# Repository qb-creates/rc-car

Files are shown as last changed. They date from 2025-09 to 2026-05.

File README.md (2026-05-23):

# RC Car Project
This project is a custom-built remote-controlled (RC) car, designed from the ground up with custom electronics, PCB design, and embedded firmware for both the car and its remote.

- Project Video (YouTube): https://youtu.be/qdBbDeDglmY
- Bidirectional Motor Driver (H-Bridge): https://en.wikipedia.org/wiki/H-bridge
- Steering Servo PWM Control: https://en.wikipedia.org/wiki/Servo_control
- nRF24L01 Wireless Transceiver Module: https://www.instructables.com/NRF24L01-Tutorial-Arduino-Wireless-Communication/

<div align="center">
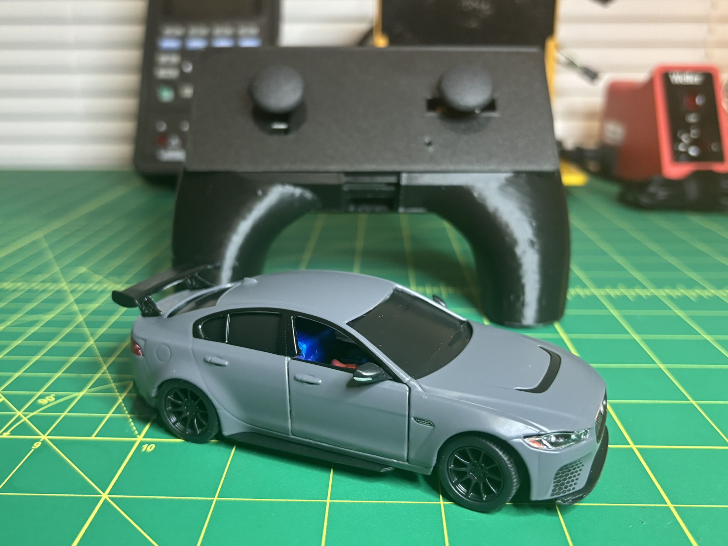
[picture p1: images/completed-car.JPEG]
Completed RC Car Side Profile
	
</div>

## Table of Contents
1. [Software Used](#software)
2. [Drive and Steering Control Circuit](#driveandsteeringcircuit)
    - [RF Receiver](#rfreceiver)
    - [Steering Servo Control](#steering)
    - [Drive Motor Control](#drivemotor)
    - [Power Consumption](#powerconsumption)
    - [Charging Notes](#carcharging)
    - [Parts List](#carpartslist)
    - [Schematics](#carschematics)
    - [PCB Images](#carpcbimages)
3. [Remote Control Circuit](#remotecontrolcircuit)
    - [RF Transmitter](#rftransmitter)
    - [Control Input Processing](#controlinputprocessing)
        - [Throttle Input (Left Analog Stick)](#throttleprocessing)
        - [Steering Input (Right Analog Stick)](#steeringprocessing)
    - [Charging Notes](#remotecharging)
    - [Parts List](#remotepartslist)
    - [Schematics](#remoteschematics)
    - [PCB Images](#remotepcbimages)
4. [Pin Mapping](#pinmapping)
    - [Car Controller (ATmega164A)](#carpinmapping)
    - [Remote Controller (ATmega164A)](#remotepinmapping)
5. [STL Viewer](#stlviewer)
    - [Car Mechanical Mounts STL](#carmechanicalmountsstl)
    - [Controller Housing STL](#controllerhousingstl)

## 1. Software Used
- VSCode with PlatformIO extension: https://docs.platformio.org/en/latest/what-is-platformio.html
- AVRDUDE (Flash Uploader): https://github.com/avrdudes/avrdude
- KiCad (PCB Design): https://www.kicad.org
- Tinkercad (Controller and parts Design): https://www.tinkercad.com/

## 2. Drive and Steering Control Circuit
This board is the car's real-time control core. It receives wireless throttle/steering commands from the handheld transmitter, converts steering targets into stable hardware PWM for the MG90S servo, and drives the rear motor through a protected H-bridge path with direction dead-time and command deadbands for smoother behavior. The result is a compact control system designed for responsive handling, predictable failsafe behavior, and reliable power delivery under changing load.

<div align="center">
 <table>
     <tr>
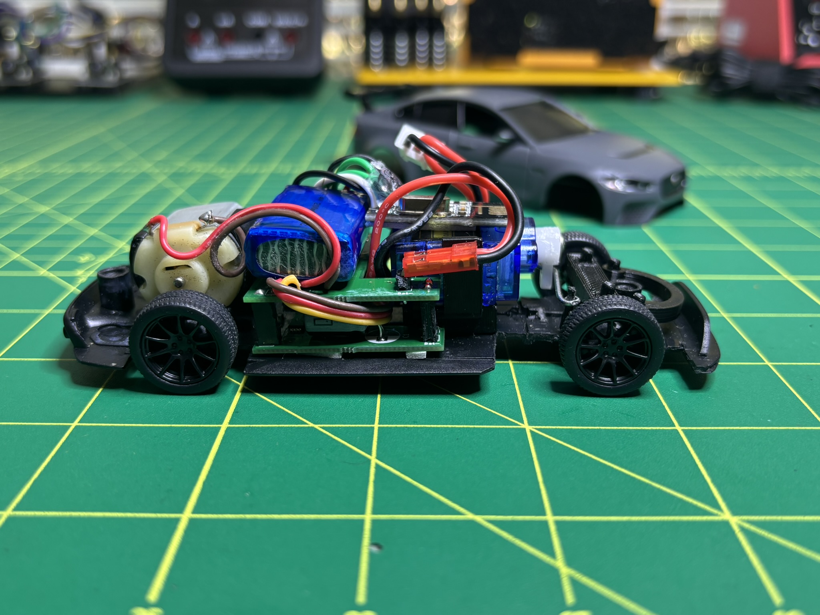
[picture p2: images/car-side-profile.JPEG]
Car Side Profile
         <td></td>
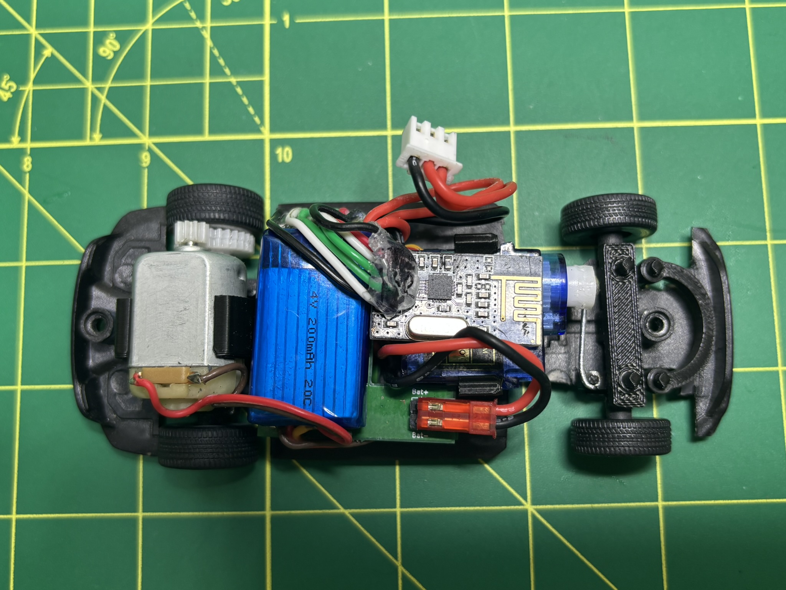
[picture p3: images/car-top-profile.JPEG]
Car Top Profile
         <td></td>
     </tr>
     <tr>
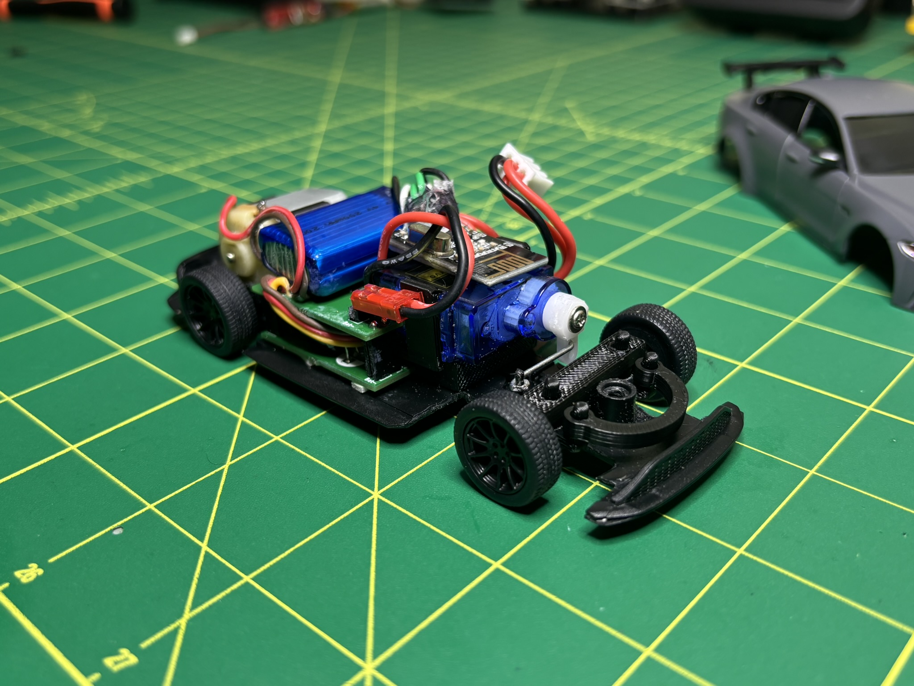
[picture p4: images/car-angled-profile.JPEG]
Car Angled Profile
         <td></td>
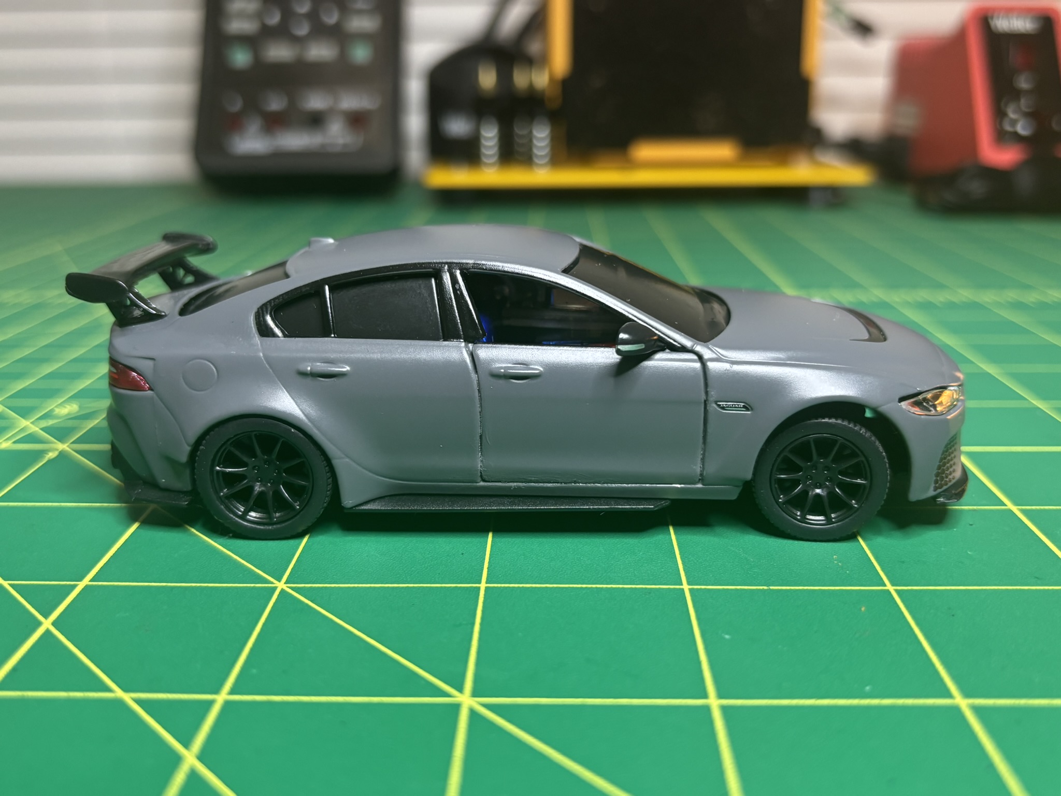
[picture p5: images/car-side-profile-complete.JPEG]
Car Side Profile Complete
         <td></td>
     </tr>
 </table>
</div>

### RF Receiver
The car uses an nRF24L01+ module with the RF24 library over SPI to receive drive and steering commands from the handheld controller. In firmware, the radio object is created as `RF24 radio(CE_PIN, CSN_PIN)` with CE on PB0 and CSN on PB1.

The RF stack is configured in `configureRFRadio()` with:

- `radio.begin()` hardware check (halts if radio is not detected)
- `radio.setPALevel(RF24_PA_LOW)` to reduce TX power/current
- `radio.enableDynamicPayloads()`
- `radio.setAutoAck(false)`
- Pipe/address setup using `"jag-1"` and `"jag-2"`
- `radio.startListening()` so this node stays in RX mode

An important part of the RF path is Timer0 timing configuration. Because this firmware includes `#include <RF24.h>`, the RF24 stack depends on `millis()`/`micros()` timing for operations such as CE pulse timing, transmit timing windows, retry timing, and transaction spacing.

The RF24 library itself does not directly configure Timer0. Instead, those timing primitives are provided by the Arduino core (`millis()`/`micros()`), and the project sets Timer0 for a 50 us timing base:

```cpp
TCCR0A = (1 << COM0B1) | (1 << WGM01) | (1 << WGM00);
TCCR0B = (1 << WGM02) | (1 << CS01); // prescaler = 8
OCR0A = 49;
```

At 8 MHz CPU clock with prescaler 8:

- Timer clock = 8 MHz / 8 = 1 MHz
- Timer tick = 1 us
- Period = (49 + 1) x 1 us = 50 us

So the Timer0 event period is 50 us (20 kHz). Timer0 is intentionally kept running at this rate so the `millis()`/`micros()` time base used by RF24 remains available and stable.

The receiver expects a `MotorControlPayload` packet with two fields:

- `int16_t ocrMotor` for signed throttle/drive command
- `uint16_t ocrSteering` for servo pulse width command in microseconds

This payload is 4 bytes total (`2 + 2`), and after reception the car firmware applies it directly:

- `OCR1B = payload.ocrSteering` for steering position
- `payload.ocrMotor` drives H-bridge direction/speed logic with a deadband of -15 to +15

Reliability/safety behavior tied to RF reception:

- On first valid packet, watchdog is enabled (`WDTO_2S`)
- Each additional valid packet resets the watchdog
- If RF packets stop arriving, watchdog timeout forces a reset/failsafe

### Steering Servo Control
Steering is driven by an MG90S servo using Timer1 hardware PWM on OC1B (PD4). The car firmware configures Timer1 in Fast PWM mode 14 with ICR1 as TOP, prescaler = 8, and ICR1 = 20000. With an 8 MHz clock, that gives a 1 us timer tick and about a 50 Hz control period (20 ms), which matches standard hobby servo timing.

The commanded steering pulse is written directly to OCR1B. Steering values are transmitted as absolute pulse widths in microseconds. Instead of assuming a fixed joystick center, the controller now supports calibration by entering measured joystick potentiometer voltages for minimum, maximum, and center. Those measured values are used to map ADC input to the steering pulse range and produce a more accurate neutral point (typically near 1900 us). On the car side, OCR1B is updated from the payload each loop:

- Neutral: calibrated from measured joystick center voltage (typically ~1900 us)
- Left/Right command range: ~1520 us to ~2280 us
- PWM period: ~20 ms (50 Hz)
- Steering deadzone: +/-90 us around calibrated center snaps to neutral to reduce twitch

This keeps steering response deterministic because the servo waveform is generated in hardware (Timer1), not by software toggling.

### Drive Motor Control
The drive motor uses a discrete H-bridge driven by a hybrid approach: latch lines select direction, while PWM is generated in software via Timer2 interrupts.

H-bridge signal assignment:

- PC0: Forward latch
- PC1: Forward PWM
- PC2: Reverse latch
- PC3: Reverse PWM

Timer2 is configured for Fast PWM with OCR2A as TOP. With OCR2A = 199 and prescaler = 8 at 8 MHz, PWM frequency is about 5 kHz. Instead of using OC2A/OC2B output pins directly, compare interrupts are used:

- TIMER2_COMPA_vect sets the active direction PWM pin high (PC1 for forward or PC3 for reverse)
- TIMER2_COMPB_vect clears that same active pin low

This effectively creates direction-dependent PWM on one of two output pins while the opposite side remains off.

Direction changes are intentionally staged to protect the bridge and drivetrain:

1. Disable Timer2 PWM (stop switching)
2. Force all H-bridge outputs low
3. Wait 150 ms dead-time
4. Assert new direction latch (PC0 forward or PC2 reverse)
5. Re-enable Timer2 PWM

That delay prevents hard instant reversals and helps ensure MOSFETs on the same side of the H-bridge are not on at the same time during direction transitions, reducing shoot-through/braking stress.

Additional control logic from the car firmware:

- Speed deadband: commands between -15 and +15 stop the motor to avoid joystick/noise creep
- Steering deadzone: commands within +/-90 us of the calibrated center are snapped to neutral
- Direction is only changed when needed (or from stopped state)
- A watchdog is enabled after first RF packet and reset on each valid packet; if RF traffic is lost, the MCU resets after the watchdog timeout (2 s)

### Why RF reception is harder with this PWM approach
Using Timer2 compare interrupts for every PWM cycle means the MCU is servicing frequent interrupts continuously while also polling and reading nRF24 payloads over SPI. That interrupt load can steal time from RF handling and make robust payload reception harder than a pure hardware-PWM motor path.

In practice, the current tuning (about 5 kHz PWM, deadband around zero, staged direction changes) was a workable sweet spot between motor smoothness and reliable radio updates. A strictly hardware PWM implementation for both drive channels would reduce ISR overhead and leave more CPU time for RF processing.

### Power Consumption
This power system was sized around worst-case drive events (motor stall plus active steering), not just average cruising current.

Estimated load envelope:

- 9V drive motor stall current at 7.2V: ~600 mA
- MG90S steering servo working current: ~600-700 mA
- Control circuitry (MCU, RF, logic, support electronics): ~20 mA

Worst-case instantaneous estimate:

- Total peak demand: $0.60 + 0.70 + 0.02 \approx 1.32\,A$

Battery capability:

- 2S 200 mAh pack, 20C rating
- Maximum continuous supply: $0.2\,Ah \times 20 = 4\,A$

Power-stage device headroom:

- IRLML6244 continuous drain current: 6.3 A (comfortably above motor stall current)
- IRLML2246 continuous source current: -1.3 A (above the ~600 mA motor stall requirement in this bridge path)

Conclusion: the battery and MOSFET current limits provide practical headroom over the expected peak load, so the system can supply drive, steering, and control electronics simultaneously under normal and transient operation.

### Charging Notes
For safe charging practice on the car side, do not charge the car while it is powered on. Turn the car off first, then connect the charger.

---
### Parts List
<div align="center">
    <table>
        <tr>
            <td valign="top">
                <table>
                    <tr><th>Part Number</th><th>Quantity</th></tr>
                    <tr><td><a href="https://www.digikey.com/en/products/detail/rubycon/25YXG220MEFC6-3X11/3134189">220uF Capacitor</a></td><td align="center">x1</td></tr>
                    <tr><td><a href="https://www.digikey.com/en/products/detail/taiyo-yuden/TMK107B7105KA-T/2714162">1uF Capacitor</a></td><td align="center">x2</td></tr>
                    <tr><td><a href="https://www.digikey.com/en/products/detail/samsung-electro-mechanics/CL21A106KAYNNNG/3894413">10uF Capacitor</a></td><td align="center">x1</td></tr>
                    <tr><td><a href="https://www.digikey.com/en/products/detail/murata-electronics/GRM188R61E225KA12D/4905349">2.2uF Capacitor</a></td><td align="center">x1</td></tr>
                    <tr><td><a href="https://www.digikey.com/en/products/detail/kemet/C0603C104K3RACTU/416044">.1uF Capacitor</a></td><td align="center">x4</td></tr>
                    <tr><td><a href="https://www.digikey.com/en/products/detail/venkel/CTL1206FRD1T/13245061">LED</a></td><td align="center">x1</td></tr>
                    <tr><td><a href="https://www.digikey.com/en/products/detail/diodes-incorporated/1N5819HW-7-F/814970">1N5819HW-7-F Diode</a></td><td align="center">x4</td></tr>
                    <tr><td><a href="https://www.amazon.com/2-54mm-Breakaway-Female-Connector-Arduino/dp/B01MQ48T2V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">Header Pins</a></td><td align="center">x17</td></tr>
                    <tr><td><a href="https://www.digikey.com/en/products/detail/onsemi/MMBT3904LT1G/919601">MMBT3904</a></td><td align="center">x2</td></tr>
                    <tr><td><a href="https://www.digikey.com/en/products/detail/umw/UMWIRLML2246TR/24889419">IRLML2246 / UMWIRLML2246TR</a></td><td align="center">x2</td></tr>
                    <tr><td><a href="https://www.digikey.com/en/products/detail/infineon-technologies/IRLML6244TRPBF/2393871">IRLML6244</a></td><td align="center">x2</td></tr>
                    <tr><td><a href="https://www.digikey.com/en/products/detail/stackpole-electronics-inc/RMCF0603FT470K/1761140">470k ohm Resistor</a></td><td align="center">x1</td></tr>
                    <tr><td><a href="https://www.digikey.com/en/products/detail/yageo/RC0603JR-07510KL/726802">500k ohm Resistor</a></td><td align="center">x1</td></tr>
                    <tr><td><a href="https://www.digikey.com/en/products/detail/koa-speer-electronics-inc/RK73B1JTTD154J/9844780">150k ohm Resistor</a></td><td align="center">x1</td></tr>
                    <tr><td><a href="https://www.digikey.com/en/products/detail/yageo/RC0603JR-071K5L/726689">1.5k ohm Resistor</a></td><td align="center">x1</td></tr>
                    <tr><td><a href="https://www.digikey.com/en/products/detail/stackpole-electronics-inc/RMCF0603JT10K0/1758104">10k ohm Resistor</a></td><td align="center">x5</td></tr>
                </table>
            </td>
            <td width="24"></td>
            <td valign="top">
                <table>
                    <tr><th>Part Number</th><th>Quantity</th></tr>
                    <tr><td><a href="https://www.digikey.com/en/products/detail/yageo/RC0603JR-071K3L/726686">1.3k ohm Resistor</a></td><td align="center">x4</td></tr>
                    <tr><td><a href="https://www.digikey.com/en/products/detail/stackpole-electronics-inc/RMCF0603FT10R0/1761152">10 ohm Resistor</a></td><td align="center">x2</td></tr>
                    <tr><td><a href="https://www.digikey.com/en/products/detail/omron-electronics-inc-emc-div/A6S-1104-PH/3102847">SW_SPST</a></td><td align="center">x1</td></tr>
                    <tr><td><a href="https://www.digikey.com/en/products/detail/texas-instruments/TPS3840DL35DBVR/15857118">TPS3840</a></td><td align="center">x1</td></tr>
                    <tr><td><a href="https://www.digikey.com/en/products/detail/microchip-technology/MIC3975-5-0YMM-TR/1029778">MIC3975-5.0YMM Voltage Regulator</a></td><td align="center">x1</td></tr>
                    <tr><td><a href="https://www.digikey.com/en/products/detail/microchip-technology/MIC5225-3-3YM5-TR/1815447">MIC5225-3.3YM5 Voltage Regulator</a></td><td align="center">x1</td></tr>
                    <tr><td><a href="https://www.digikey.com/en/products/detail/microchip-technology/ATMEGA164A-AU/2271202">ATmega164A-A</a></td><td align="center">x1</td></tr>
                    <tr><td><a href="https://www.amazon.com/dp/B0BWJ4RKGV?ref=ppx_yo2ov_dt_b_fed_asin_title">MG90S servo motor</a></td><td align="center">x1</td></tr>
                    <tr><td><a href="https://www.amazon.com/uxcell-Micro-11500-12000RPM-Remote-Control/dp/B07M99JK6Y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">9V DC Motor</a></td><td align="center">x1</td></tr>
                    <tr><td><a href="https://www.amazon.com/KiNSMART-Jaguar-Project-Metal-Model/dp/B0GXDP3B83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">Kinsmart Jaguar 1:38</a></td><td align="center">x1</td></tr>
                    <tr><td><a href="https://www.amazon.com/HiLetgo-NRF24L01-Wireless-Transceiver-Module/dp/B00LX47OCY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">NRF24L01+ Module</a></td><td align="center">x1</td></tr>
                    <tr><td><a href="https://www.amazon.com/dp/B07MW2L96L?ref=ppx_yo2ov_dt_b_fed_asin_title">7.4V battery</a></td><td align="center">x1</td></tr>
                    <tr><td><a href="https://www.amazon.com/200PCS-Module-Plastic-Single-Spindle/dp/B0DKHG96PL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">Gears</a></td><td align="center">x1</td></tr>
                    <tr><td><a href="https://www.amazon.com/ruthex-Threaded-Insert-pieces-ultrasound/dp/B088QJG676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">M2 Inserts</a></td><td align="center">x3</td></tr>
                    <tr><td><a href="https://www.amazon.com/Phillips-Countersunk-Electronic-Accessories-Samsung/dp/B07HC3LQYS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">M2 screws</a></td><td align="center">x3</td></tr>
                </table>
            </td>
        </tr>
    </table>
</div>

### Schematics
<div align="center">
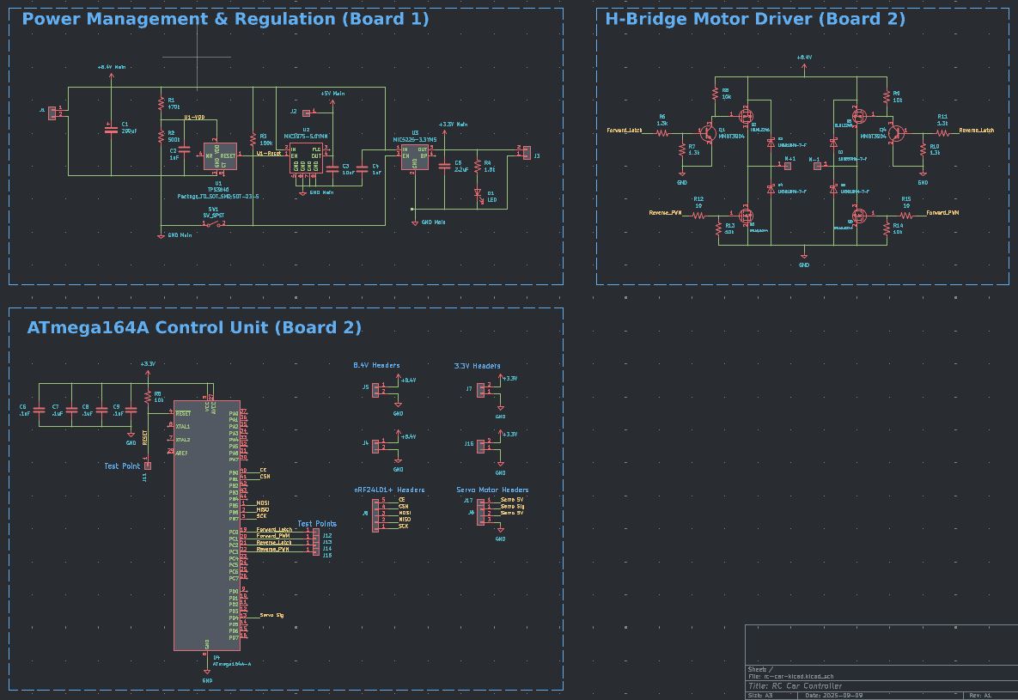
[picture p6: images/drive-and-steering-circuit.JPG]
Drive and Steering Circuit
    
</div>

### PCB Images
<div align="center">
 <table>
     <tr>
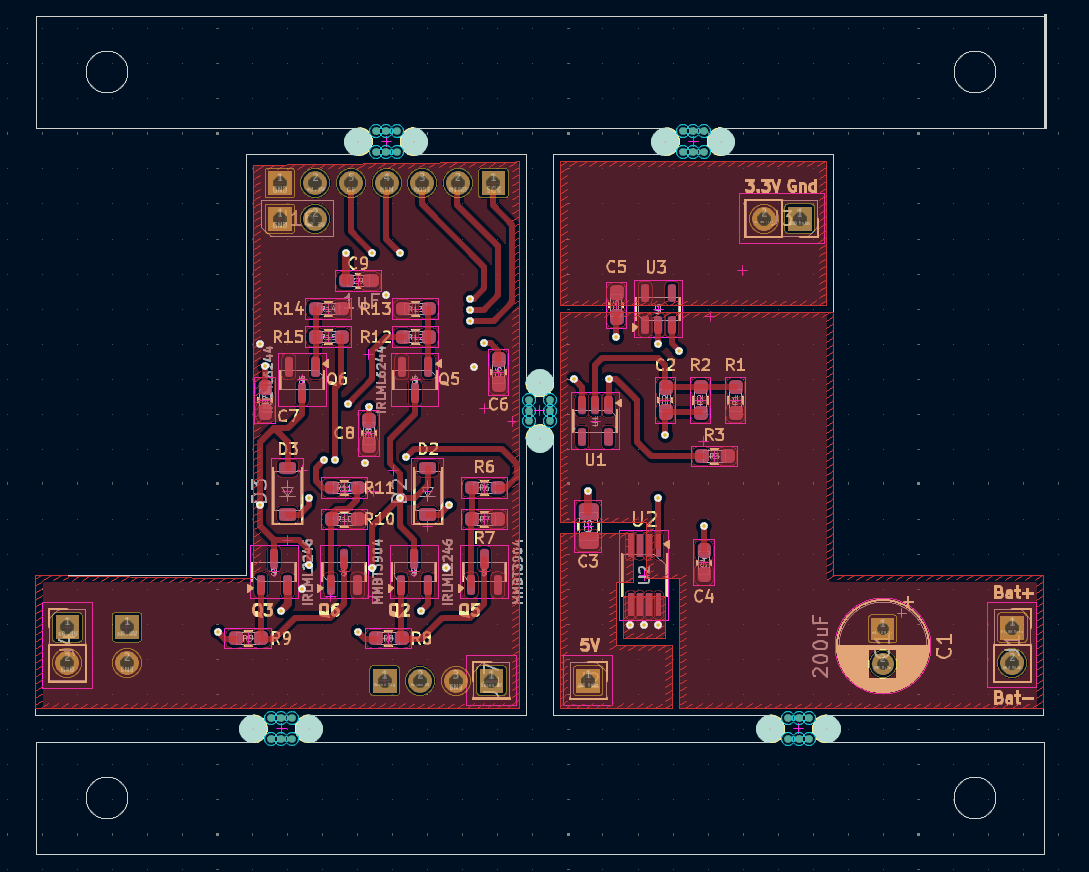
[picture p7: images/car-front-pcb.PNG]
Car Front PCB
         <td></td>
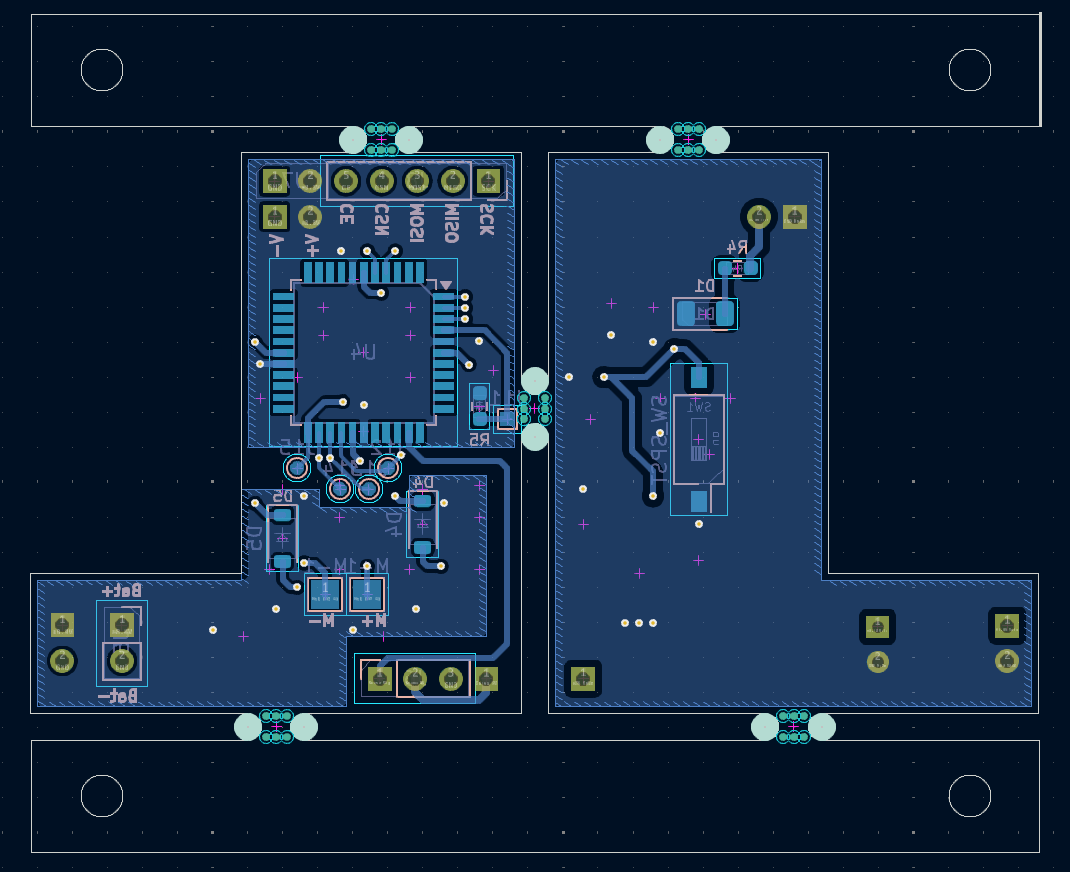
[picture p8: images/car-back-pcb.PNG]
Car Back PCB
         <td></td>
     </tr>
     <tr>
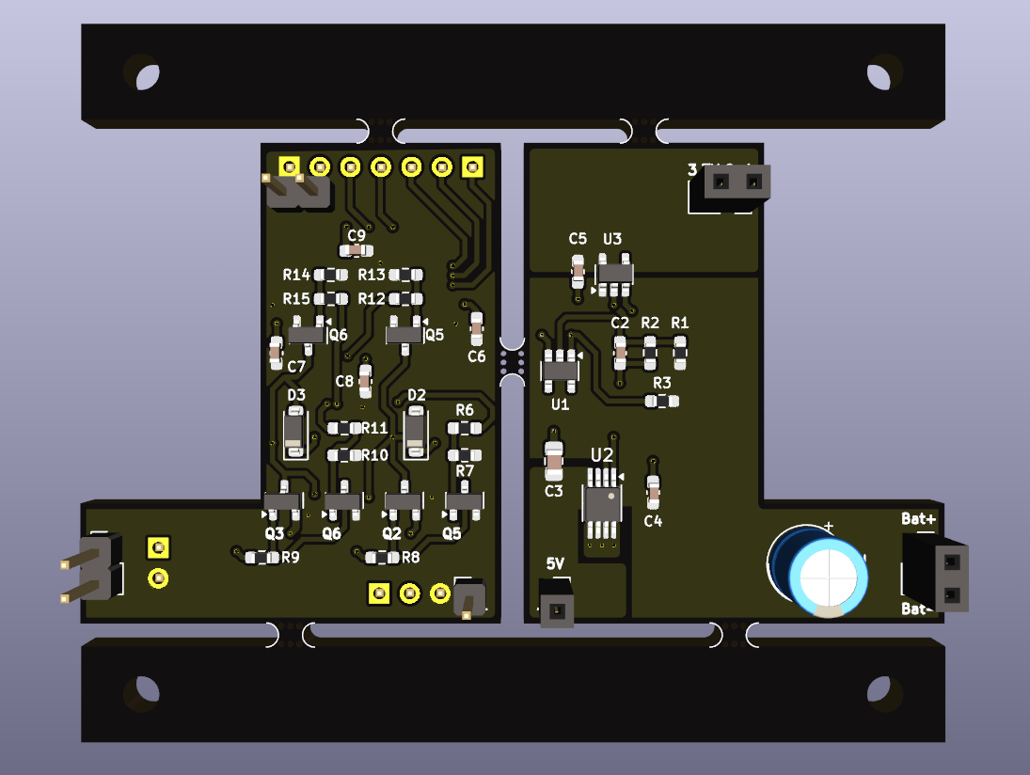
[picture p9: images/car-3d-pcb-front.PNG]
Car 3D PCB Front
         <td></td>
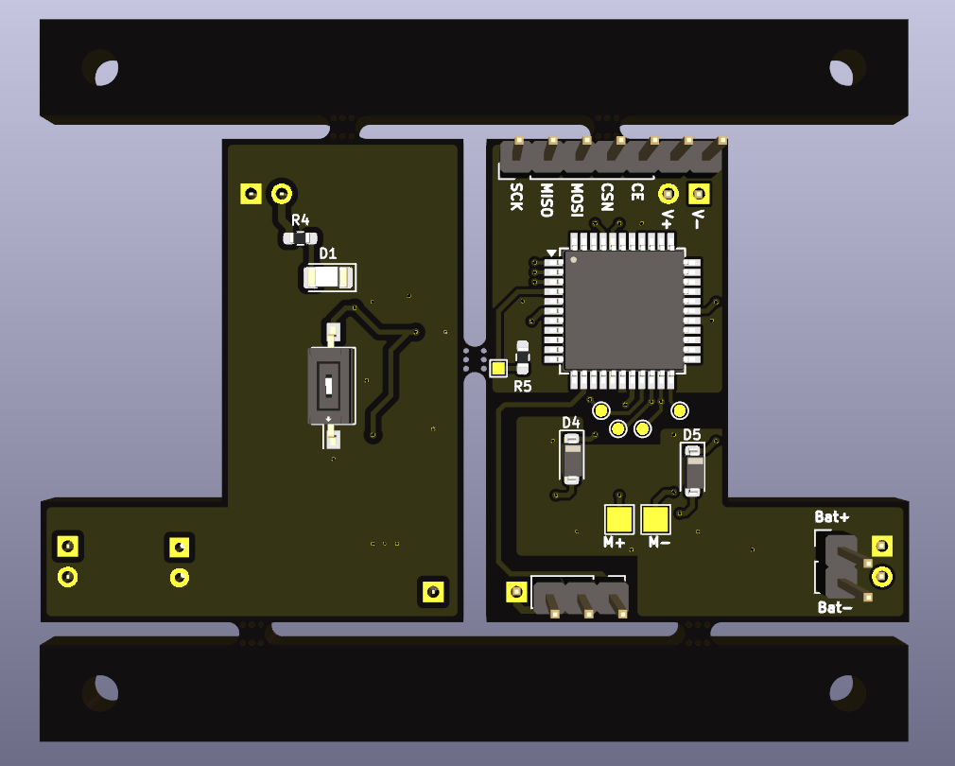
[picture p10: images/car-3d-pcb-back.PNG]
Car 3D PCB Back
         <td></td>
     </tr>
 </table>
</div>

## 3. Remote Control Circuit
The handheld controller samples two joystick axes, converts them into throttle and steering commands, and transmits those values over 2.4 GHz to the car at a steady update rate. The design goal is low-latency control with stable center behavior so the car tracks driver input without twitching or drift.

<div align="center">
 <table>
     <tr>
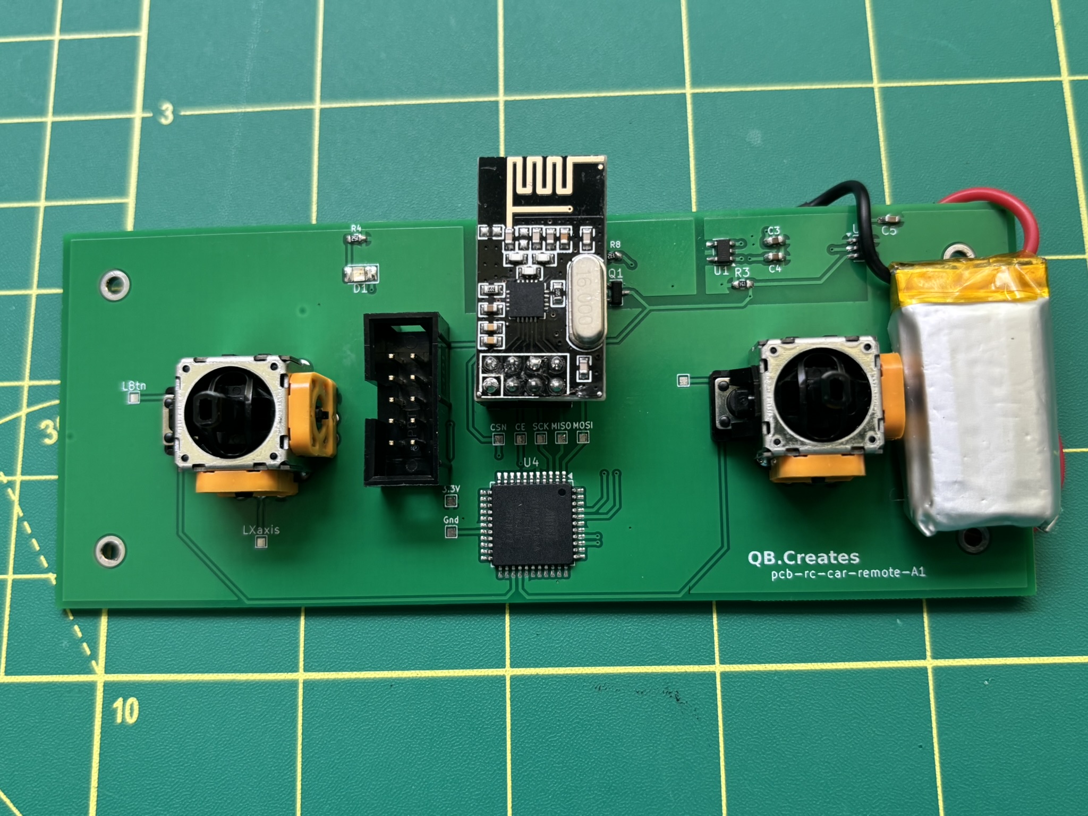
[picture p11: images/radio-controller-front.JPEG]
Radio Controller Front
         <td></td>
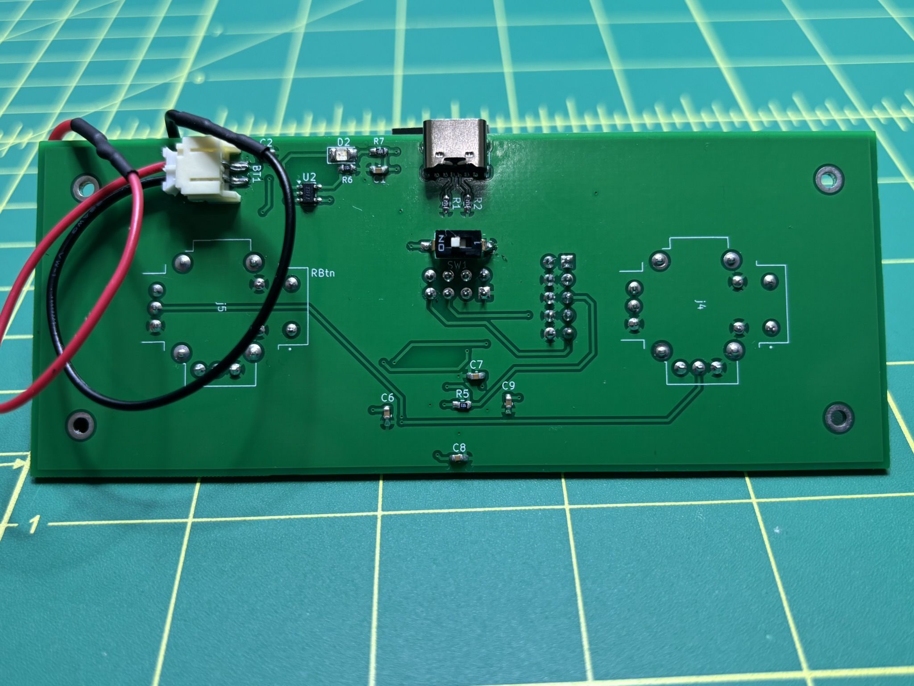
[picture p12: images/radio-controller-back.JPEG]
Radio Controller Back
         <td></td>
     </tr>
     <tr>
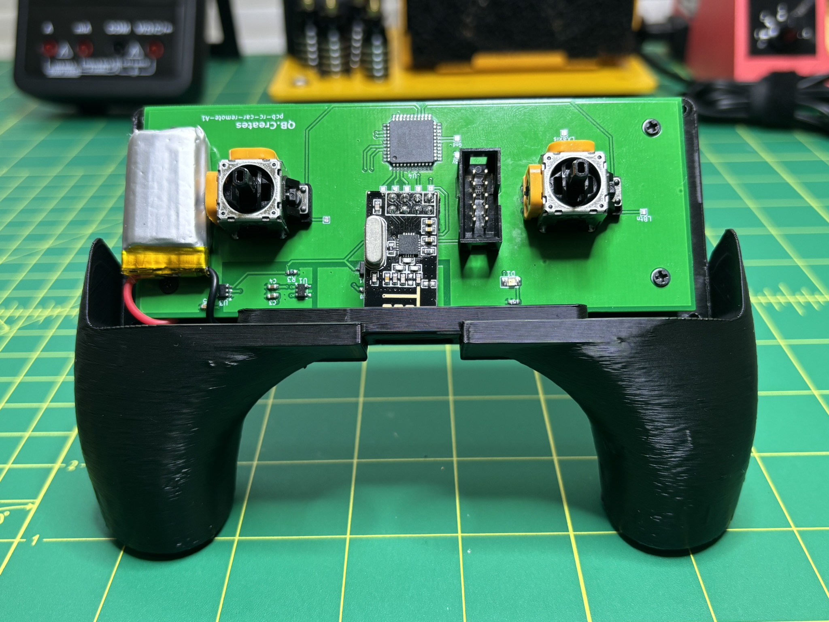
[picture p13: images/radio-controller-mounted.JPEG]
Radio Controller Mounted
         <td></td>
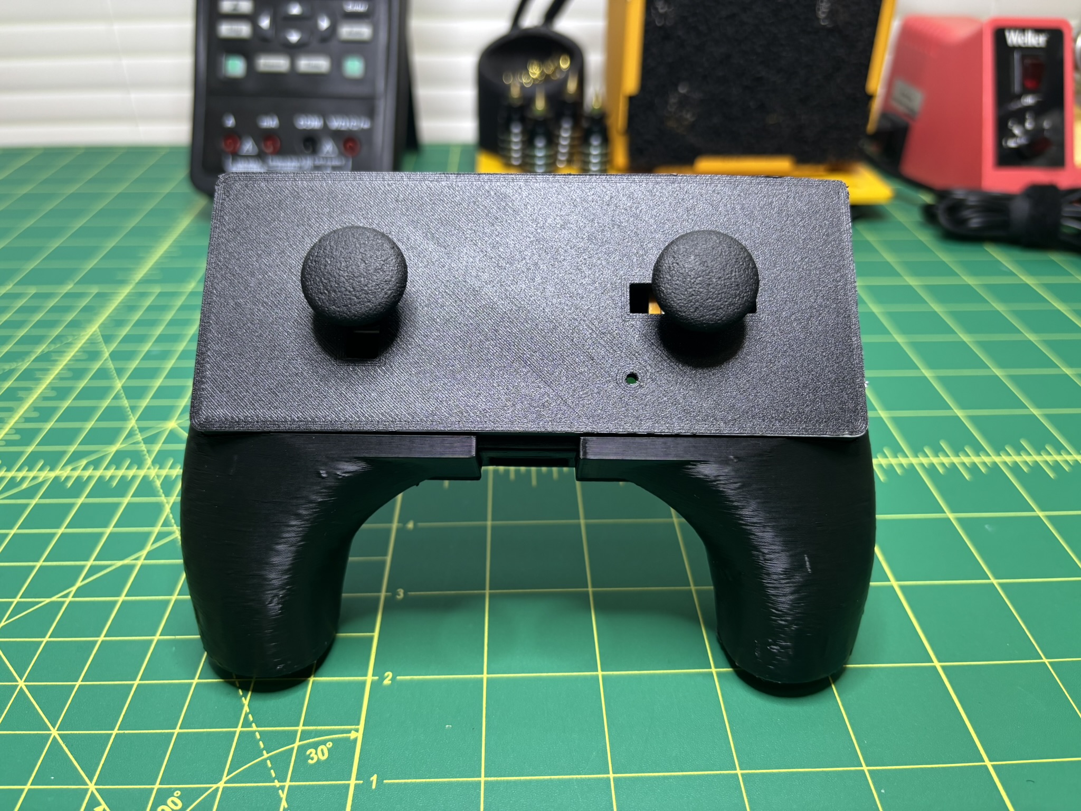
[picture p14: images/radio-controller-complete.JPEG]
Radio Controller Complete
         <td></td>
     </tr>
 </table>
</div>

### RF Transmitter
The remote uses an nRF24L01+ module with RF24 over SPI to transmit `MotorControlPayload` packets containing `ocrMotor` and `ocrSteering`. During initialization, firmware performs a radio hardware check, configures dynamic payload mode, and sets TX/RX addresses for the paired node. Timer0 is also configured with a 50 us base so the `millis()`/`micros()` timing used by RF24 remains stable while packets are sent continuously.

### Control Input Processing
Joystick values are read through the ADC and mapped into the exact command domains expected by the vehicle firmware. This preprocessing keeps control semantics consistent across the RF link: signed throttle around zero and steering in absolute pulse-width units centered at a calibrated neutral.

#### Throttle Input (Left Analog Stick)
Throttle is sampled on ADC channel 0, inverted to match intuitive stick direction, scaled into a signed drive command, and centered around zero. Positive values represent forward demand, negative values represent reverse demand, and near-zero commands cooperate with the car-side deadband to prevent idle creep.

#### Steering Input (Right Analog Stick)
Steering is sampled on ADC channel 1 and converted using a calibration profile where measured joystick potentiometer minimum, maximum, and center voltages are entered in firmware. The mapping uses those measured endpoints and center value to generate steering pulses, then clamps to the valid steering window before transmission. This makes neutral alignment and left/right travel more accurate than a fixed center assumption. A center deadzone is applied so small stick jitter and ADC noise snap back to neutral, reducing servo chatter and improving straight-line stability.

To measure and enter steering calibration voltages:

1. Power the controller on.
2. Connect the multimeter to ground and to the X-axis test point by the left controller.
3. Measure the voltage with the analog stick in its center position (center voltage).
4. Measure the voltage with the stick moved all the way to the right (minimum voltage for this mapping).
5. Measure the voltage with the stick moved all the way to the left (maximum voltage for this mapping).

### Charging Notes
The remote has a built-in LiPo charging circuit. When a charger is connected, the controller may automatically power on while charging. You can place the power switch in the OFF position before charging if you prefer it to stay off.

---
### Parts List
<div align="center">
    <table>
        <tr>
            <td valign="top">
                <table>
                    <tr><th>Part Number</th><th>Quantity</th></tr>
                    <tr><td><a href="https://www.digikey.com/en/products/detail/jst-sales-america-inc/S2B-PH-SM4-TB/926655">JST Connector</a></td><td align="center">x1</td></tr>
                    <tr><td><a href="https://www.digikey.com/en/products/detail/samsung-electro-mechanics/CL10A475KP8NNNC/3886702">4.7uF Capacitor</a></td><td align="center">x2</td></tr>
                    <tr><td><a href="https://www.digikey.com/en/products/detail/taiyo-yuden/TMK107B7105KA-T/2714162">1uF Capacitor</a></td><td align="center">x2</td></tr>
                    <tr><td><a href="https://www.digikey.com/en/products/detail/murata-electronics/GRM188R61E225KA12D/4905349">2.2uF Capacitor</a></td><td align="center">x1</td></tr>
                    <tr><td><a href="https://www.digikey.com/en/products/detail/kemet/C0603C104K3RACTU/416044">.1uF Capacitor</a></td><td align="center">x4</td></tr>
                    <tr><td><a href="https://www.digikey.com/en/products/detail/venkel/CTL1206FRD1T/13245061">LED</a></td><td align="center">x2</td></tr>
                    <tr><td><a href="https://www.digikey.com/en/products/detail/gct/USB4125-GF-A/13547384">USB_C_Receptacle_USB2.0_14P</a></td><td align="center">x1</td></tr>
                    <tr><td><a href="https://www.digikey.com/en/products/detail/w-rth-elektronik/61201021621/2060590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">AVR-ISP-10</a></td><td align="center">x1</td></tr>
                    <tr><td><a href="https://www.amazon.com/2-54mm-Breakaway-Female-Connector-Arduino/dp/B01MQ48T2V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">nRF24L01+ Headers</a></td><td align="center">x1</td></tr>
                    <tr><td><a href="https://www.amazon.com/Automation-Joysticks-Compatible-Controllers-Precision/dp/B09Y2R1GLV">Joystick B09Y2R1GLV</a></td><td align="center">x2</td></tr>
                    <tr><td><a href="https://www.digikey.com/en/products/detail/infineon-technologies/IRLML6244TRPBF/2393871">IRLML6244</a></td><td align="center">x1</td></tr>
                    <tr><td><a href="https://www.digikey.com/en/products/detail/yageo/RC0603FR-075K1L/727268">5.1k ohm Resistor</a></td><td align="center">x2</td></tr>
                    <tr><td><a href="https://www.digikey.com/en/products/detail/koa-speer-electronics-inc/RK73B1JTTD154J/9844780">150k ohm Resistor</a></td><td align="center">x1</td></tr>
                </table>
            </td>
            <td width="24"></td>
            <td valign="top">
                <table>
                    <tr><th>Part Number</th><th>Quantity</th></tr>
                    <tr><td><a href="https://www.digikey.com/en/products/detail/yageo/RC0603JR-071K5L/726689">1.5k ohm Resistor</a></td><td align="center">x1</td></tr>
                    <tr><td><a href="https://www.digikey.com/en/products/detail/stackpole-electronics-inc/RMCF0603JT10K0/1758104">10k ohm Resistor</a></td><td align="center">x2</td></tr>
                    <tr><td><a href="https://www.digikey.com/en/products/detail/yageo/RC0603FR-07330RL/727162">330 ohm Resistor</a></td><td align="center">x1</td></tr>
                    <tr><td><a href="https://www.digikey.com/en/products/detail/yageo/RC0603JR-071K3L/726686">1.3k ohm Resistor</a></td><td align="center">x1</td></tr>
                    <tr><td><a href="https://www.digikey.com/en/products/detail/omron-electronics-inc-emc-div/A6S-1104-PH/3102847">SW_SPST</a></td><td align="center">x1</td></tr>
                    <tr><td><a href="https://www.digikey.com/en/products/detail/texas-instruments/TPS3840DL35DBVR/15857118">TPS3840</a></td><td align="center">x1</td></tr>
                    <tr><td><a href="https://www.digikey.com/en/products/detail/microchip-technology/MCP73831T-4ADI-OT/1874437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">MCP73831-2-OT</a></td><td align="center">x1</td></tr>
                    <tr><td><a href="https://www.digikey.com/en/products/detail/microchip-technology/MIC5225-3-3YM5-TR/1815447">MIC5225-3.3YM5 Voltage Regulator</a></td><td align="center">x1</td></tr>
                    <tr><td><a href="https://www.digikey.com/en/products/detail/microchip-technology/ATMEGA164A-AU/2271202">ATmega164A-A</a></td><td align="center">x1</td></tr>
                    <tr><td><a href="https://www.amazon.com/HiLetgo-NRF24L01-Wireless-Transceiver-Module/dp/B00LX47OCY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">NRF24L01+ Module</a></td><td align="center">x1</td></tr>
                    <tr><td><a href="https://www.amazon.com/EEMB-Rechargeable-Connector-Parrott-Polarity/dp/B0B7R8CS2C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">3.7v battery</a></td><td align="center">x1</td></tr>
                    <tr><td><a href="https://www.amazon.com/ruthex-Threaded-Insert-pieces-ultrasound/dp/B088QJG676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">M2 Inserts</a></td><td align="center">x10</td></tr>
                    <tr><td><a href="https://www.amazon.com/Phillips-Countersunk-Electronic-Accessories-Samsung/dp/B07HC3LQYS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">M2 Screws</a></td><td align="center">x10</td></tr>
                </table>
            </td>
        </tr>
    </table>
</div>

### Schematics
<div align="center">
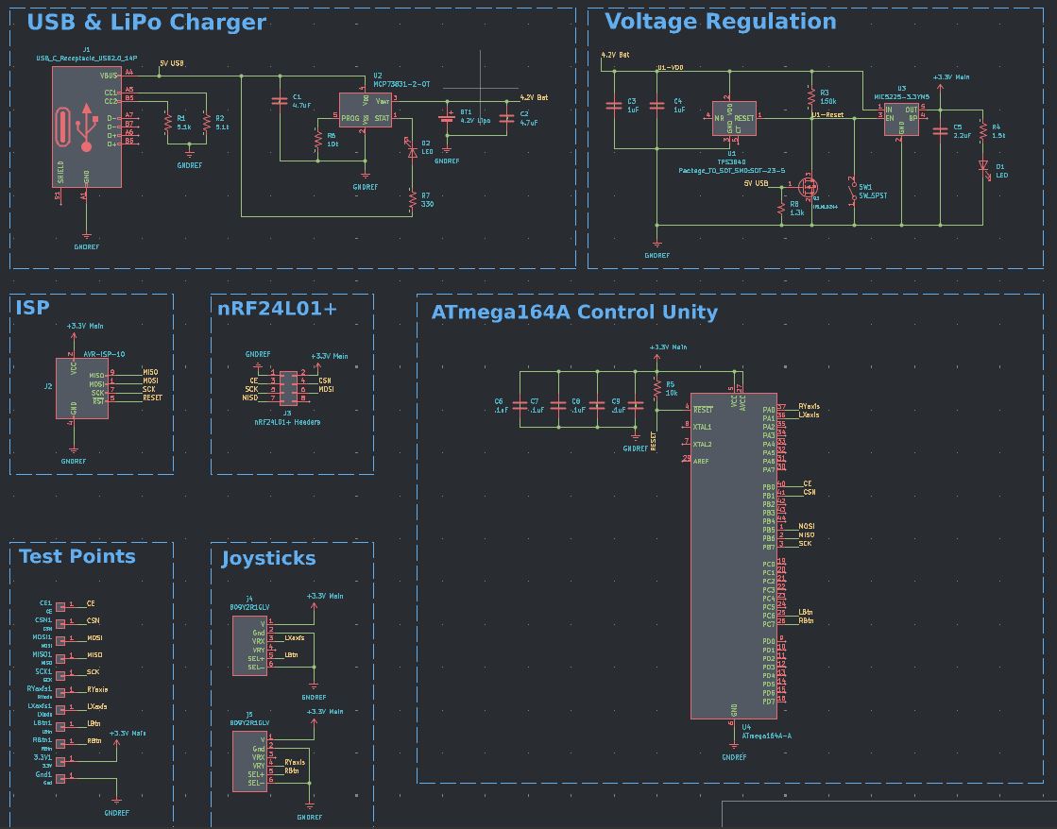
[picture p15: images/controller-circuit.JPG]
Controller Circuit
    
</div>

### PCB Images
<div align="center">
 <table>
     <tr>
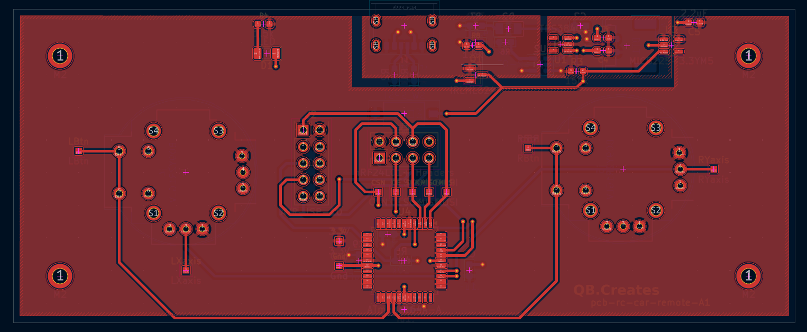
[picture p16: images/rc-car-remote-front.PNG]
RC Car Remote Front PCB
         <td></td>
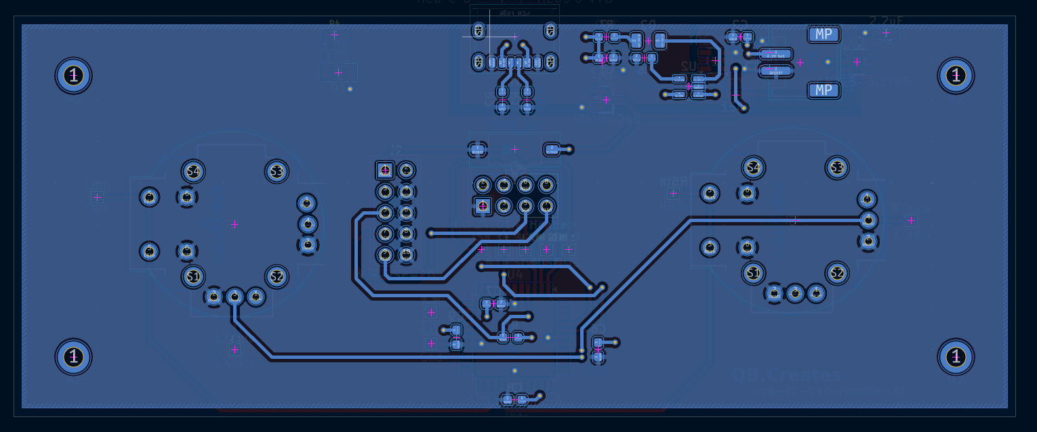
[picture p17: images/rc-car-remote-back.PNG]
RC Car Remote Back PCB
         <td></td>
     </tr>
     <tr>
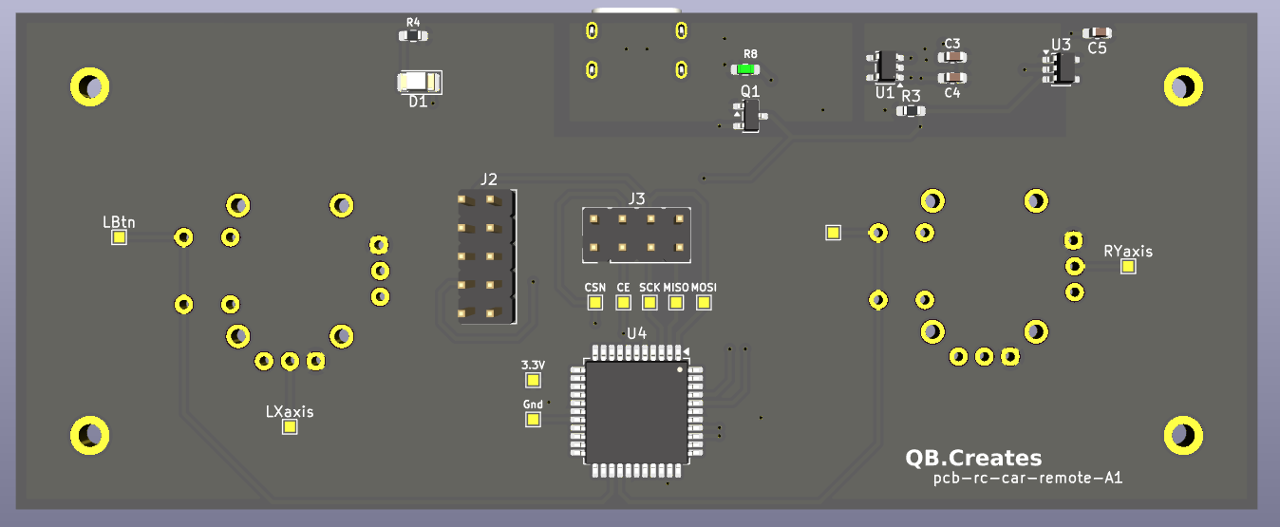
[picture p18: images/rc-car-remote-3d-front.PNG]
RC Car Remote 3D PCB Front
         <td></td>
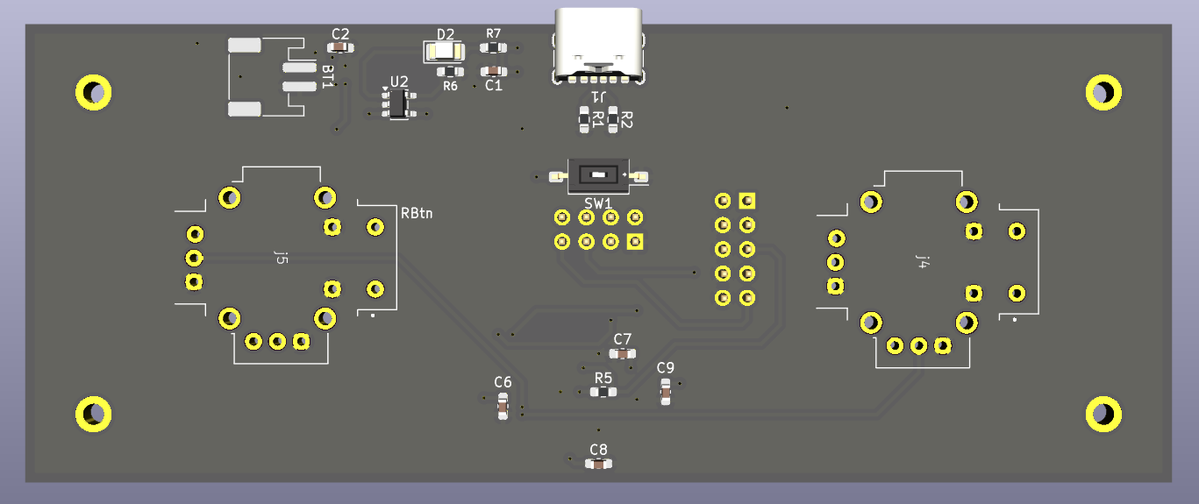
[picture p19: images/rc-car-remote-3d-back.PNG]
RC Car Remote 3D PCB Back
         <td></td>
     </tr>
 </table>
</div>

## 4. Pin Mapping 
ATmega164A/P pin information is from the Microchip datasheet: https://ww1.microchip.com/downloads/en/devicedoc/atmel-8272-8-bit-avr-microcontroller-atmega164a_pa-324a_pa-644a_pa-1284_p_datasheet.pdf

### Car Controller (ATmega164A)
| Signal | MCU Pin | Notes |
|:--|:--|:--|
| nRF24 CE | PB0 | Defined as `CE_PIN 0` in car RF firmware |
| nRF24 CSN | PB1 | Defined as `CSN_PIN 1` in car RF firmware |
| nRF24 SPI SCK | PB7 | Hardware SPI clock |
| nRF24 SPI MISO | PB6 | Hardware SPI MISO |
| nRF24 SPI MOSI | PB5 | Hardware SPI MOSI |
| nRF24 SPI SS | PB4 | Hardware SPI SS |
| Steering PWM (OC1B) | PD4 | Servo output (Timer1 OC1B) |
| Motor Forward Latch | PC0 | H-bridge control |
| Motor Forward PWM | PC1 | H-bridge control |
| Motor Reverse Latch | PC2 | H-bridge control |
| Motor Reverse PWM | PC3 | H-bridge control |
| Status LED | PD5 | Set during startup/status |

### Remote Controller (ATmega164A)
| Signal | MCU Pin | Notes |
|:--|:--|:--|
| nRF24 CE | PB0 | Defined as `CE_PIN 0` in remote RF firmware |
| nRF24 CSN | PB1 | Defined as `CSN_PIN 1` in remote RF firmware |
| nRF24 SPI SCK | PB7 | Hardware SPI clock |
| nRF24 SPI MISO | PB6 | Hardware SPI MISO |
| nRF24 SPI MOSI | PB5 | Hardware SPI MOSI |
| nRF24 SPI SS | PB4 | Hardware SPI SS |
| Throttle Joystick (Y) ADC | PA0 / ADC0 | Read with `readADC(0)` |
| Steering Joystick (X) ADC | PA1 / ADC1 | Read with `readADC(1)` |

## 5. STL Viewer 
### Car Mechanical Mounts STL 
- [Car Parts.stl](3d%20print/Car%20Parts.stl)

### Controller Housing STL 
- [Controller.stl](3d%20print/Controller.stl)

---

## License
See [LICENSE](LICENSE) for details.

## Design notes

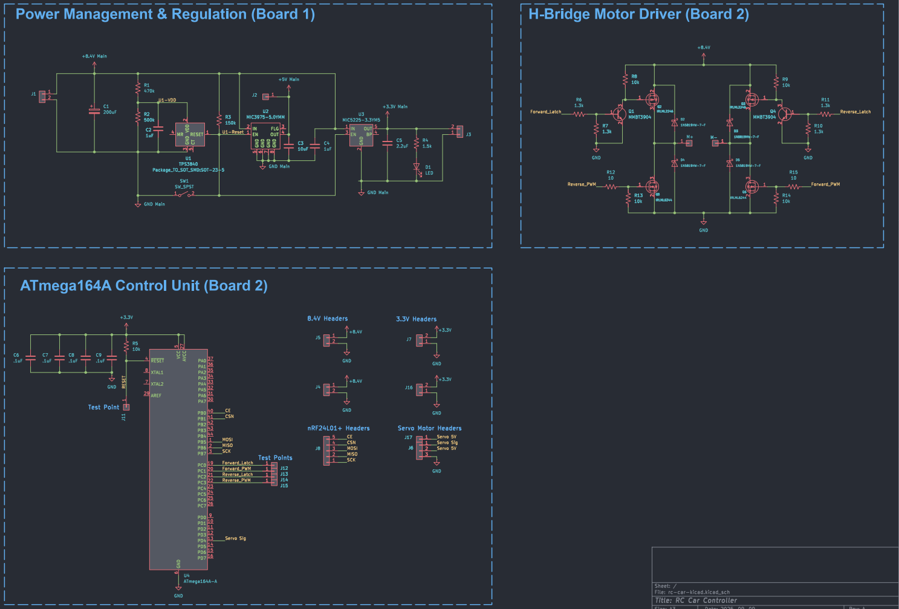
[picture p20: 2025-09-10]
images/schematic.PNG

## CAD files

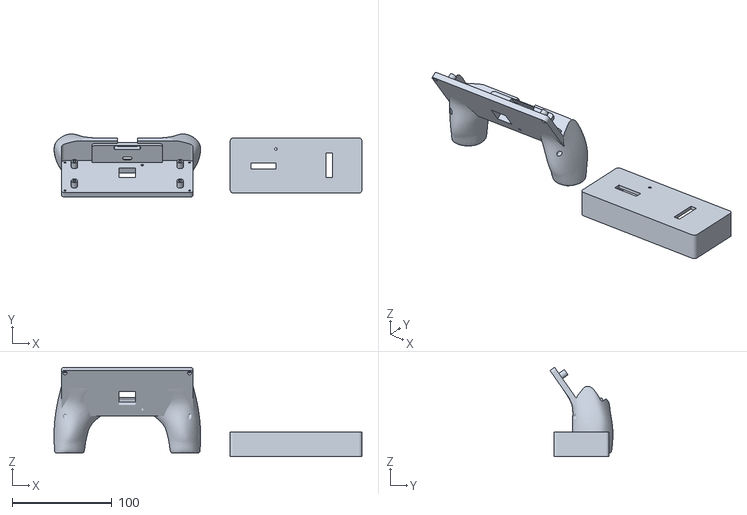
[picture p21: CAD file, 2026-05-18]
3d print/Controller.stl
308.9 x 63.2 x 89.7

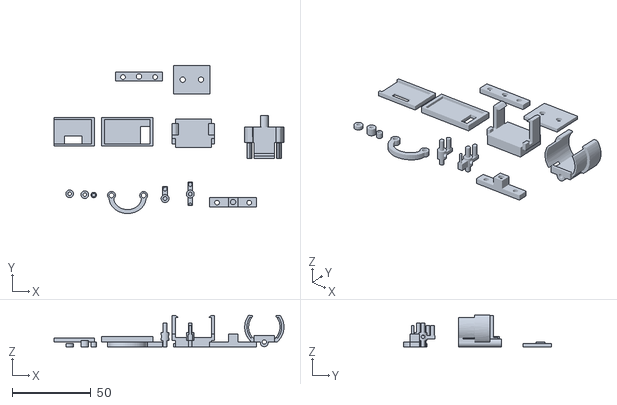
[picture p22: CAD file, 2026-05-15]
3d print/Car Parts.stl
146.0 x 94.0 x 20.0

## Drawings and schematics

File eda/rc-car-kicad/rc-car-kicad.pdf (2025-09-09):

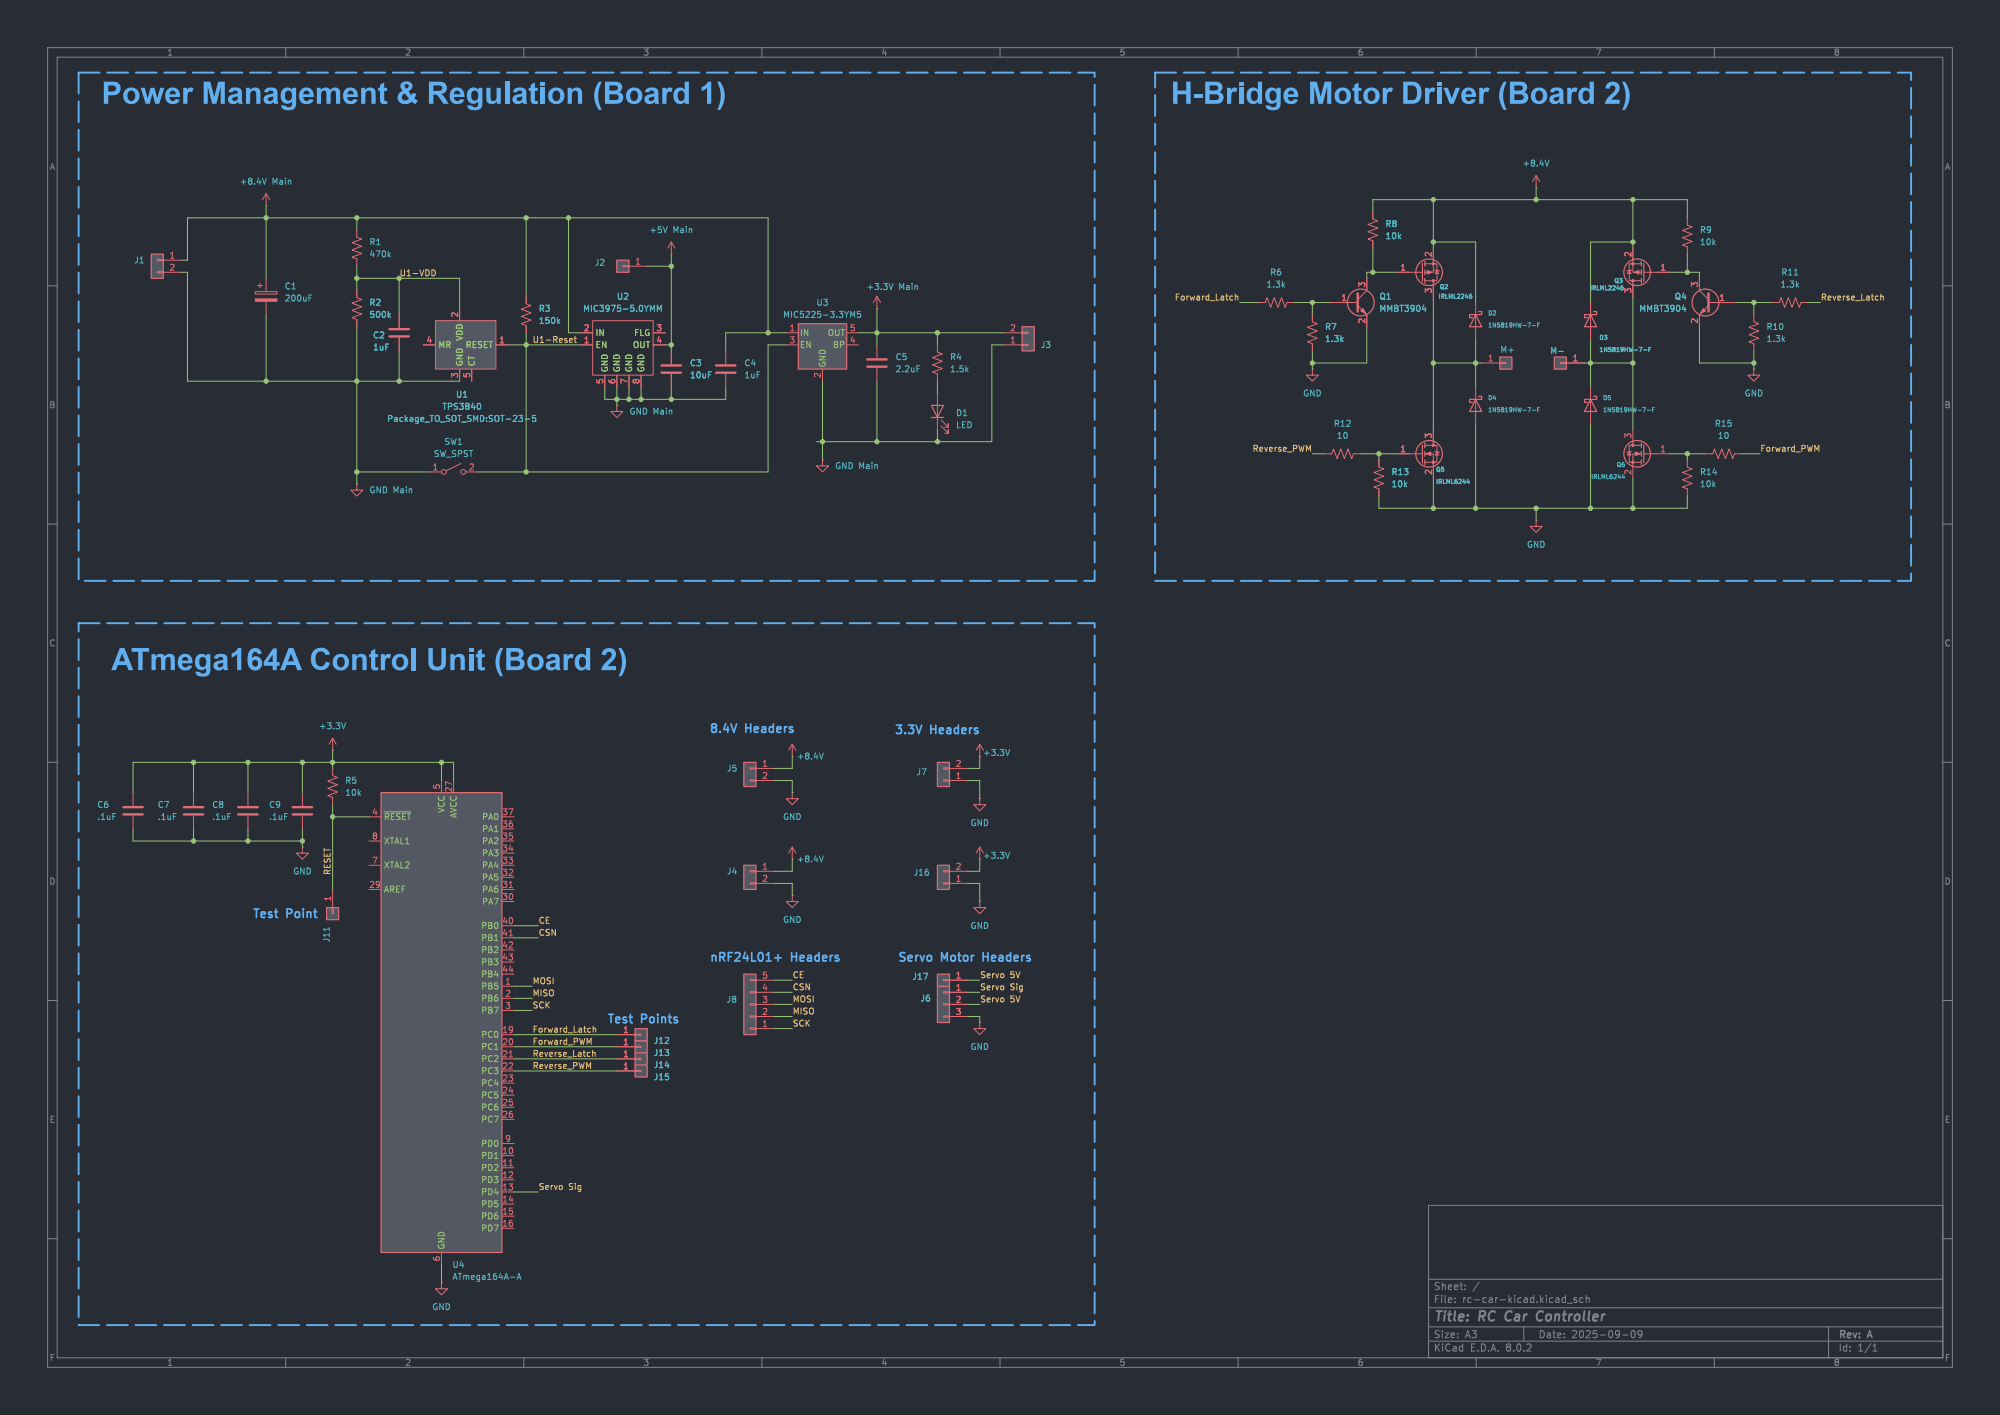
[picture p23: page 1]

Forward_Latch Power Management & Regulation (Board 1)

H-Bridge Motor Driver (Board 2)

2 EN 3 BP 4 OUT 5 U3 MIC5225-3.3YM5 GND Main C3

Id: 1/1 Title: RC Car Controller File: rc-car-kicad.kicad_sch Sheet: /

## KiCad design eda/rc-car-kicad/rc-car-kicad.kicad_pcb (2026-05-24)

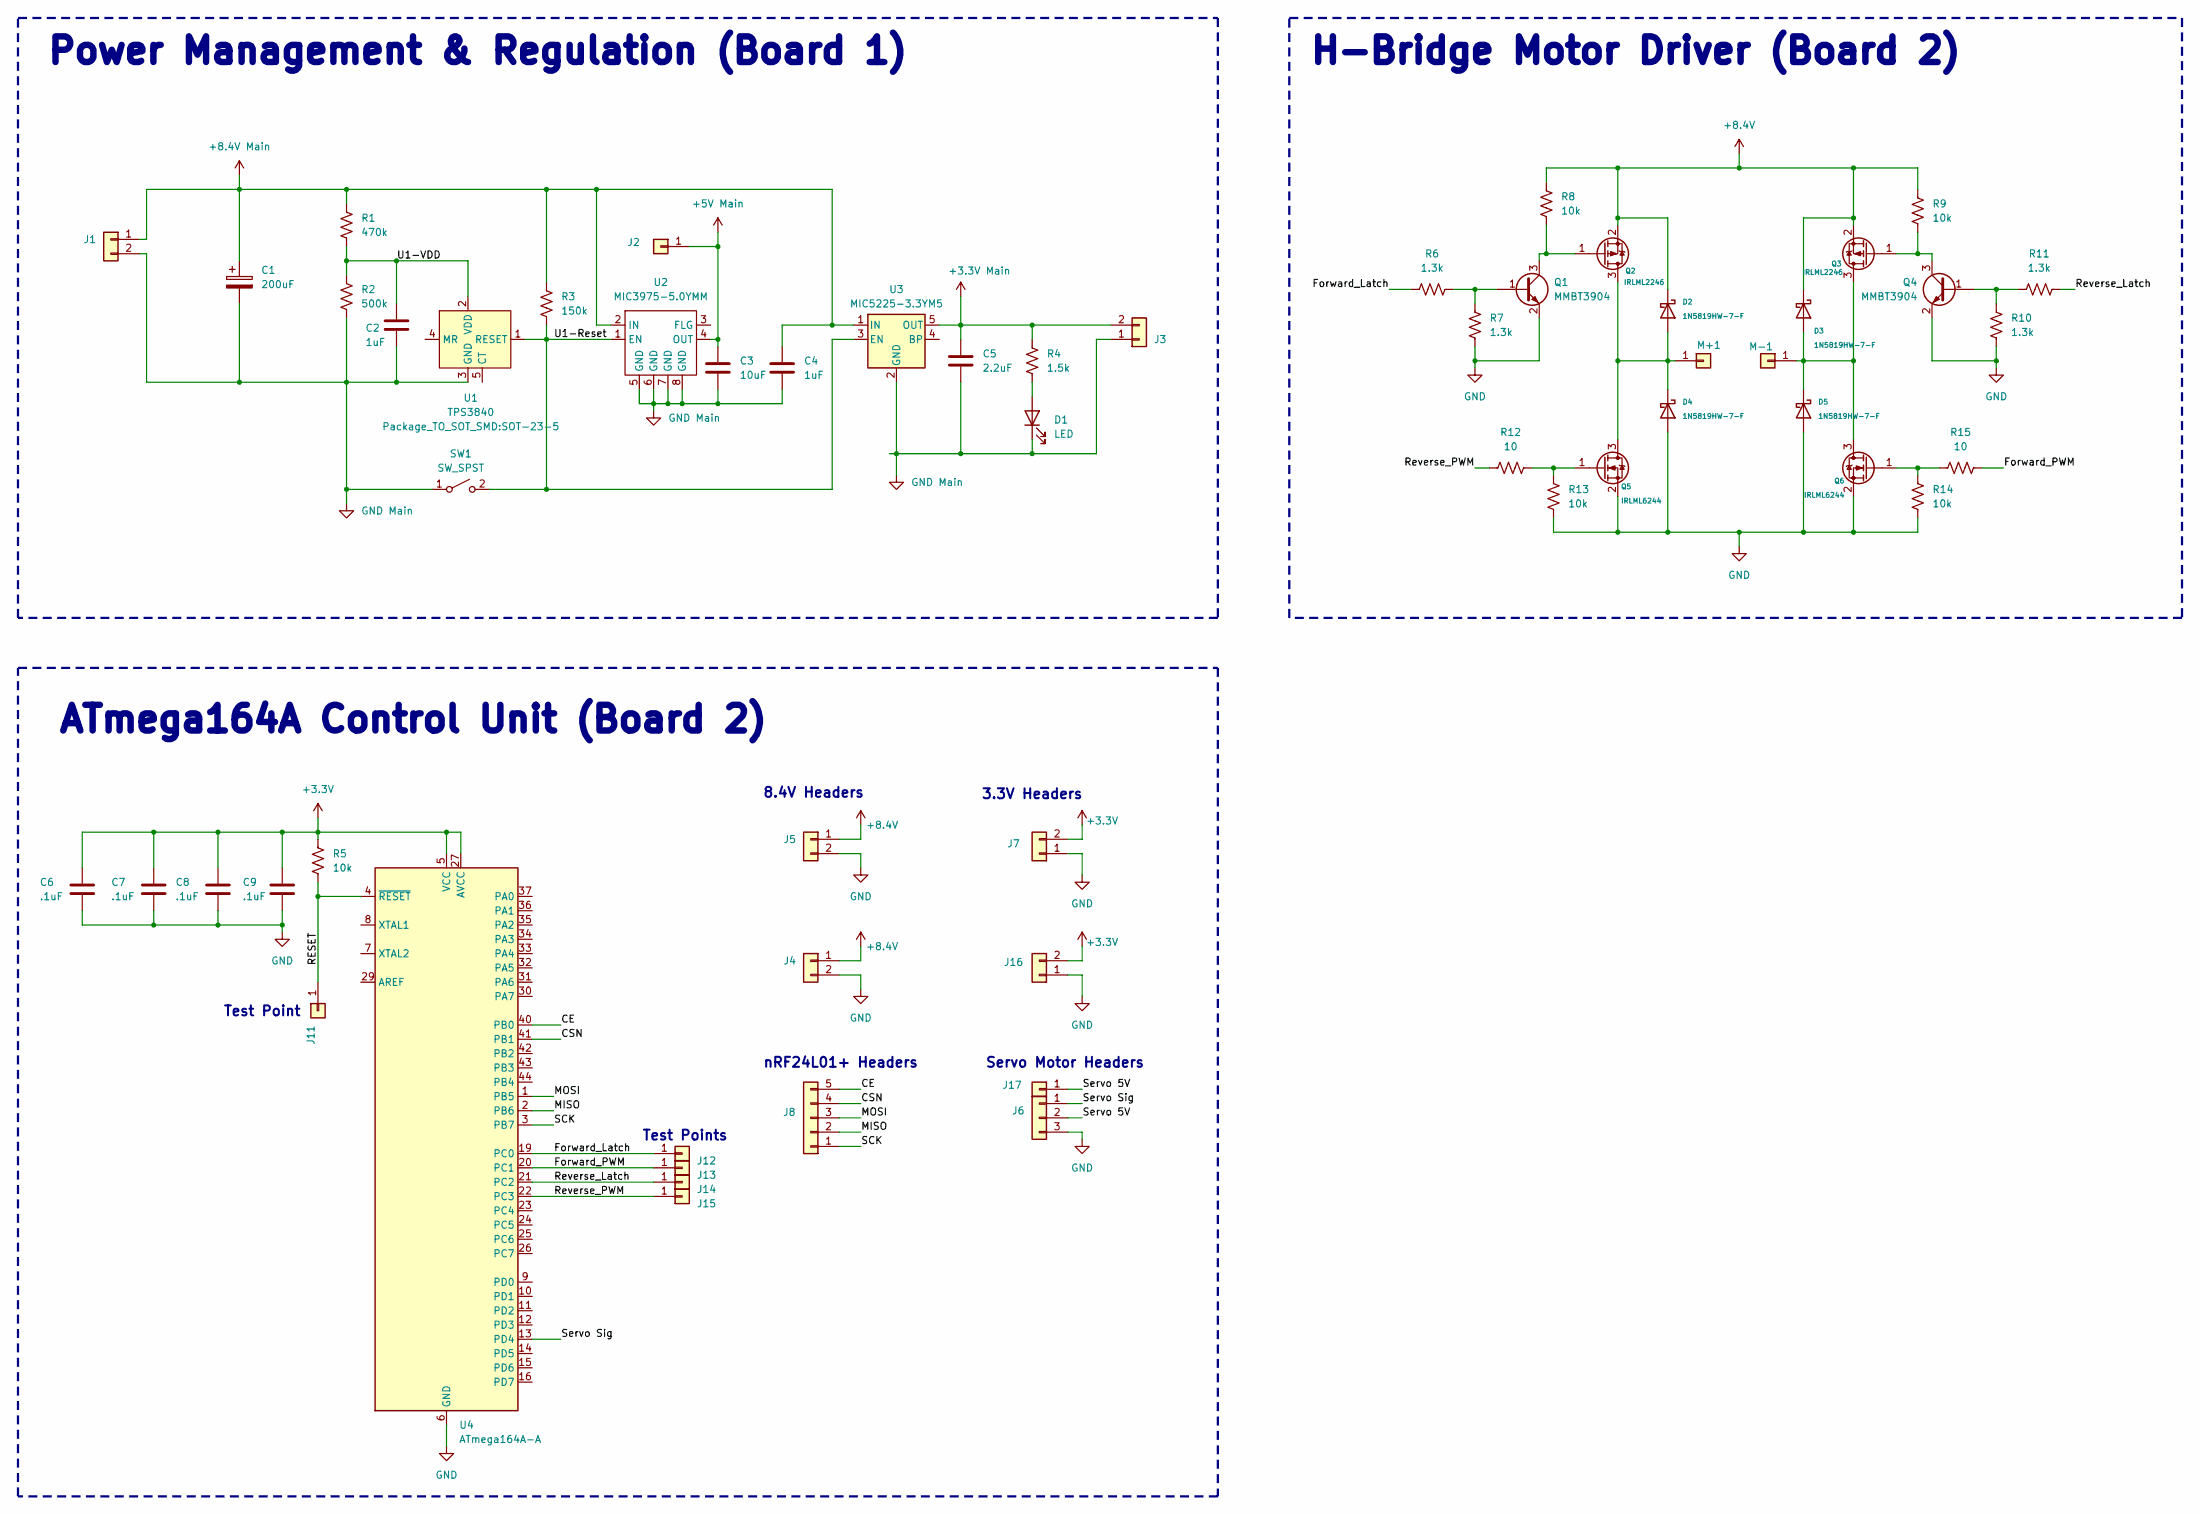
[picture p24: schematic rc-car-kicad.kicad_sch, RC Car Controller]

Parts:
C1: 200uF; CP_Radial_D6.3mm_P2.50mm
C2, C4: 1uF; C_0603_1608Metric_Pad1.08x0.95mm_HandSolder
C3: 10uF; C_0805_2012Metric_Pad1.18x1.45mm_HandSolder
C5: 2.2uF; C_0603_1608Metric_Pad1.08x0.95mm_HandSolder
C6, C7, C8, C9: .1uF; C_0603_1608Metric_Pad1.08x0.95mm_HandSolder
D1: LED; LED_1206_3216Metric
D2, D3, D4, D5: 1N5819HW-7-F; D_SOD-123
J1, J3: PinSocket_1x02_P2.54mm_Vertical
J2: PinSocket_1x01_P2.54mm_Vertical
J4, J5: PinHeader_1x02_P2.54mm_Vertical
J6: PinHeader_1x03_P2.54mm_Vertical
J7, J16: PinHeader_1x02_P2.54mm_Vertical_No_Courtyard
J8: PinHeader_1x05_P2.54mm_Vertical
J11: TestPoint_Pad_1.0x1.0mm
J12, J13, J14, J15: TestPoint_Pad_D1.0mm
J17: PinHeader_1x01_P2.54mm_Vertical
M+1: TestPoint_Pad_2.0x2.0mm
M-1: TestPoint_Pad_2.0x2.0mm
Q1, Q4: MMBT3904; SOT-23
Q2, Q3: IRLML2246; SOT-23
Q5, Q6: IRLML6244; SOT-23
R1: 470k; R_0603_1608Metric_Pad0.98x0.95mm_HandSolder
R2: 500k; R_0603_1608Metric_Pad0.98x0.95mm_HandSolder
R3: 150k; R_0603_1608Metric_Pad0.98x0.95mm_HandSolder
R4: 1.5k; R_0603_1608Metric_Pad0.98x0.95mm_HandSolder
R5, R8, R9, R13, R14: 10k; R_0603_1608Metric_Pad0.98x0.95mm_HandSolder
R6, R7, R10, R11: 1.3k; R_0603_1608Metric_Pad0.98x0.95mm_HandSolder
R12, R15: 10; R_0603_1608Metric_Pad0.98x0.95mm_HandSolder
SW1: SW_SPST; SW_DIP_SPSTx01_Slide_Omron_A6S-110x_W8.9mm_P2.54mm
U1: TPS3840; SOT-23-5
U2: MIC3975-5.0YMM; MSOP-8_3x3mm_P0.65mm
U3: MIC5225-3.3YM5; SOT-23-5
U4: ATmega164A-A; TQFP-44_10x10mm_P0.8mm

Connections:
+3.3V: C6.1, C7.1, C8.1, C9.1, J7.2, J16.2, R5.1, U4.5 (VCC), U4.17 (VCC), U4.27 (AVCC), U4.38 (VCC)
+3.3V Main: C5.1, J3.2, R4.2, U3.5 (OUT)
+5V Main: C3.1, J2.1, U2.4 (OUT)
+8.4V: D2.1 (K), D3.1 (K), J4.1, J5.1, Q2.2 (S), Q3.2 (S), R8.1, R9.1
+8.4V Main: C1.1, C4.1, J1.1, R1.1, R3.1, U2.2 (IN), U3.1 (IN)
/CE: J8.5, U4.40 (PB0)
/CSN: J8.4, U4.41 (PB1)
/Forward_Latch: J12.1, R6.1, U4.19 (PC0)
/Forward_PWM: J13.1, R15.2, U4.20 (PC1)
/MISO: J8.2, U4.2 (PB6)
/MOSI: J8.3, U4.1 (PB5)
/RESET: J11.1, R5.2, U4.4 (~RESET)
/Reverse_Latch: J14.1, R11.2, U4.21 (PC2)
/Reverse_PWM: J15.1, R12.1, U4.22 (PC3)
/SCK: J8.1, U4.3 (PB7)
/Servo 5V: J6.2, J17.1
/Servo Sig: J6.1, U4.13 (PD4)
/U1-Reset: R3.2, SW1.2 (B), U1.1 (RESET), U2.1 (EN), U3.3 (EN)
/U1-VDD: C2.1, R1.2, R2.1, U1.2 (VDD)
GND: C6.2, C7.2, C8.2, C9.2, D4.2 (A), D5.2 (A), J4.2, J5.2, J6.3, J7.1, J16.1, Q1.2 (E), Q4.2 (E), Q5.2 (S), Q6.2 (S), R7.2, R10.2, R13.2, R14.2, U4.6 (GND), U4.18 (GND), U4.28 (GND), U4.39 (GND)
GND Main: C1.2, C2.2, C3.2, C4.2, C5.2, D1.1 (K), J1.2, J3.1, R2.2, SW1.1 (A), U1.3 (GND), U2.5 (GND), U2.6 (GND), U2.7 (GND), U2.8 (GND), U3.2 (GND)
unnamed: D1.2 (A), R4.1
unnamed: D2.2 (A), D4.1 (K), M+1.1, Q2.3 (D), Q5.3 (D)
unnamed: D3.2 (A), D5.1 (K), M-1.1, Q3.3 (D), Q6.3 (D)
unnamed: Q1.1 (B), R6.2, R7.1
unnamed: Q1.3 (C), Q2.1 (G), R8.2
unnamed: Q3.1 (G), Q4.3 (C), R9.2
unnamed: Q4.1 (B), R10.1, R11.1
unnamed: Q5.1 (G), R12.2, R13.1
unnamed: Q6.1 (G), R14.1, R15.1

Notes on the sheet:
H-Bridge Motor Driver (Board 2)
8.4V Headers
Test Points
nRF24L01+ Headers
Test Point
3.3V Headers
ATmega164A Control Unit (Board 2)
Power Management & Regulation (Board 1)
Servo Motor Headers

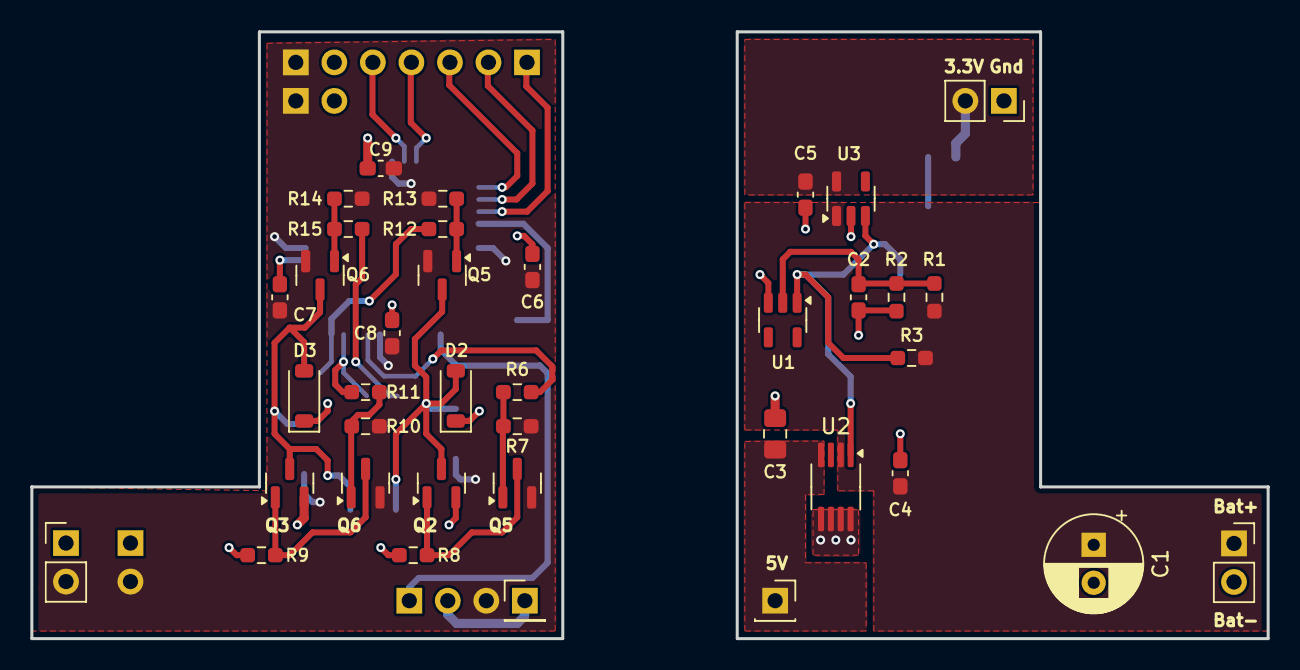
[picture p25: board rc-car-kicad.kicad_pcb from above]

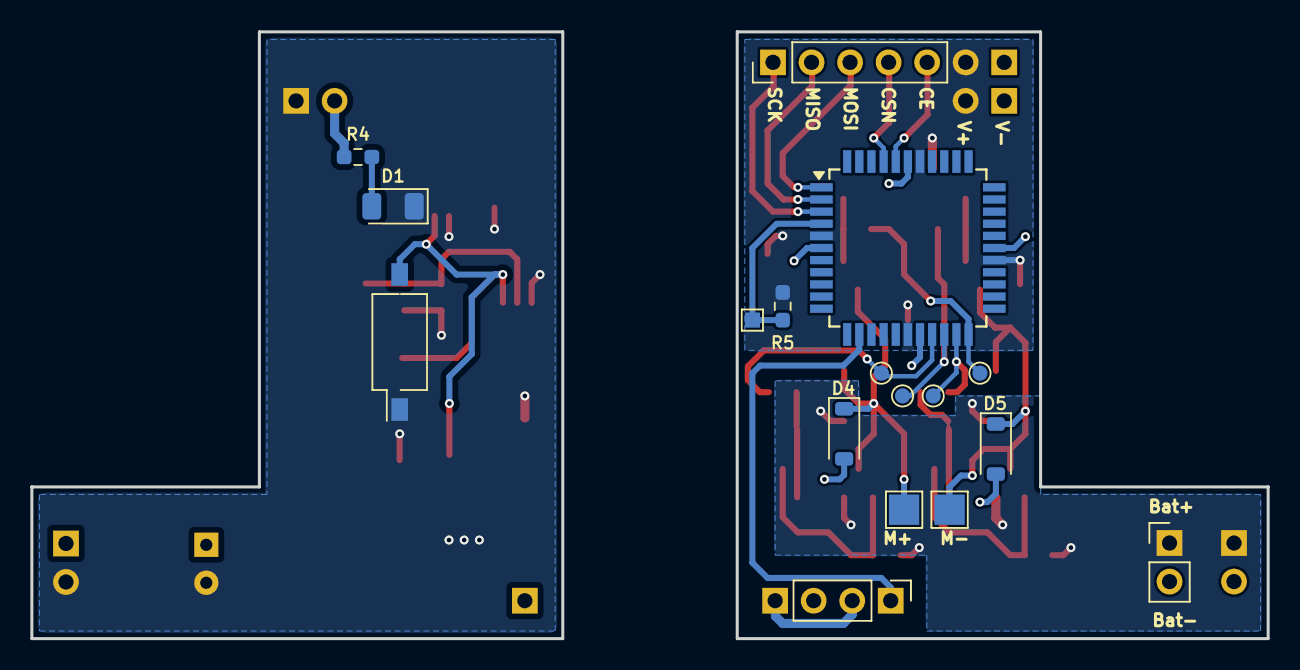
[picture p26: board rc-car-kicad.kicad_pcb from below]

Board: 2 copper layers, 81.5 x 40.0 mm, 57 parts (18 on the bottom side), 30 nets.

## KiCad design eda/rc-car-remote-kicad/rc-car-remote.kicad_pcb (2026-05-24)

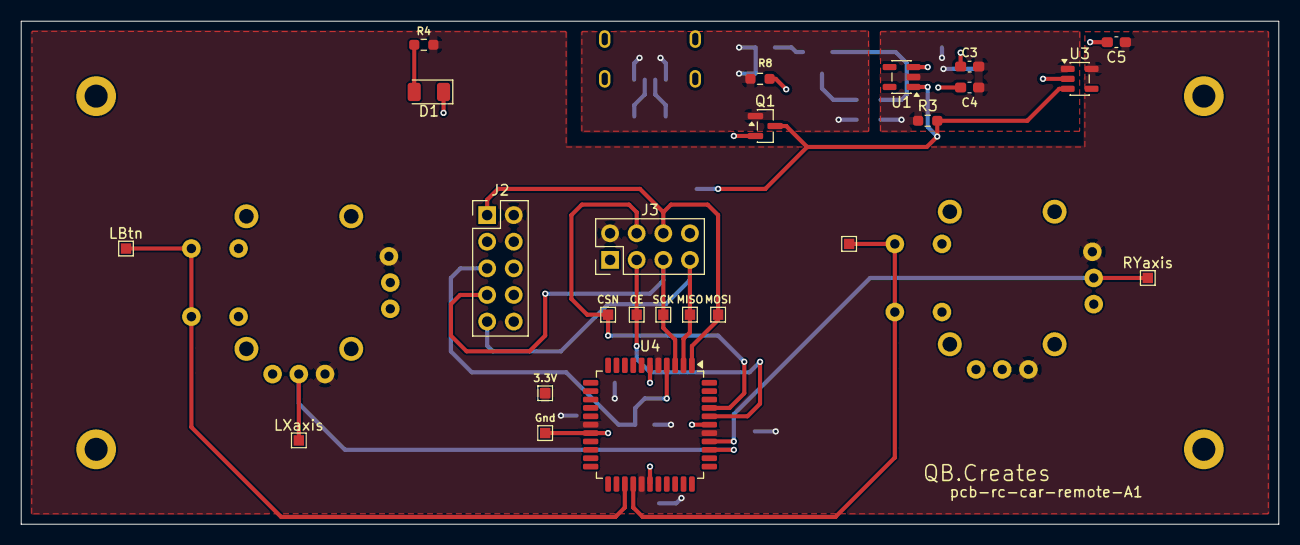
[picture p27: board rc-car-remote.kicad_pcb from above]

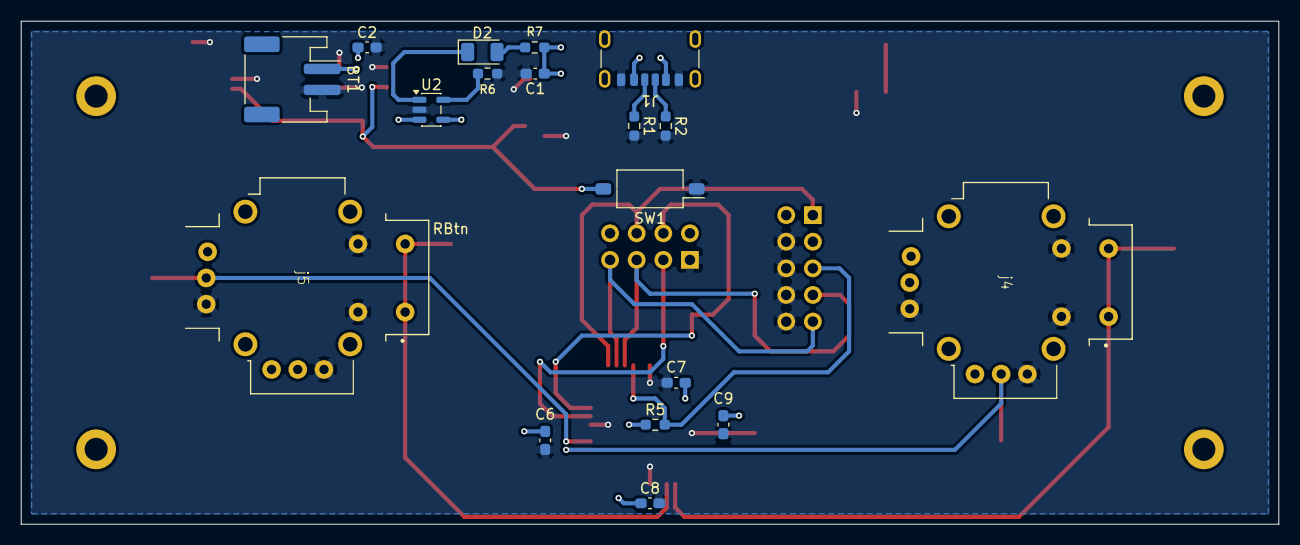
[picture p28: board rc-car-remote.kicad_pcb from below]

Board: 2 copper layers, 120.0 x 48.0 mm, 42 parts (18 on the bottom side), 21 nets.

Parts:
3.3V: 3.3V; TestPoint_Pad_1.0x1.0mm
BT1: 4.2V Lipo; JST_PH_S2B-PH-SM4-TB_1x02-1MP_P2.00mm_Horizontal
C1, C2: 4.7uF; C_0603_1608Metric_Pad1.08x0.95mm_HandSolder
C3, C4: 1uF; C_0603_1608Metric_Pad1.08x0.95mm_HandSolder
C5: 2.2uF; C_0603_1608Metric_Pad1.08x0.95mm_HandSolder
C6, C7, C8, C9: .1uF; C_0603_1608Metric_Pad1.08x0.95mm_HandSolder
CE: CE; TestPoint_Pad_1.0x1.0mm
CSN: CSN; TestPoint_Pad_1.0x1.0mm
D1, D2: LED; LED_1206_3216Metric
Gnd: Gnd; TestPoint_Pad_1.0x1.0mm
J1: USB_C_Receptacle_USB2.0_14P; USB_C_Receptacle_GCT_USB4125-xx-x-0190_6P_TopMnt_Horizontal
J2: AVR-ISP-10; PinHeader_2x05_P2.54mm_Vertical
J3: nRF24L01+ Headers; PinHeader_2x04_P2.54mm_Vertical
LBtn: LBtn; TestPoint_Pad_1.0x1.0mm
LXaxis: LXaxis; TestPoint_Pad_1.0x1.0mm
MISO: MISO; TestPoint_Pad_1.0x1.0mm
MOSI: MOSI; TestPoint_Pad_1.0x1.0mm
Q1: IRLML6244; SOT-23
R1, R2: 5.1k; R_0603_1608Metric_Pad0.98x0.95mm_HandSolder
R3: 150k; R_0603_1608Metric_Pad0.98x0.95mm_HandSolder
R4: 1.5k; R_0603_1608Metric_Pad0.98x0.95mm_HandSolder
R5, R6: 10k; R_0603_1608Metric_Pad0.98x0.95mm_HandSolder
R7: 330; R_0603_1608Metric_Pad0.98x0.95mm_HandSolder
R8: 1.3k; R_0603_1608Metric_Pad0.98x0.95mm_HandSolder
RBtn: RBtn; TestPoint_Pad_1.0x1.0mm
RYaxis: RYaxis; TestPoint_Pad_1.0x1.0mm
SCK: SCK; TestPoint_Pad_1.0x1.0mm
SW1: SW_SPST; SW_DIP_SPSTx01_Slide_Omron_A6S-110x_W8.9mm_P2.54mm
U1: TPS3840; SOT-23-5
U2: MCP73831-2-OT; SOT-23-5
U3: MIC5225-3.3YM5; SOT-23-5
U4: ATmega164A-A; TQFP-44_10x10mm_P0.8mm
j4, j5: B09Y2R1GLV; Jao B09Y2R1GLV

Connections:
+3.3V Main: 3.3V.1 (Pin_1_1), C5.1, C6.1, C7.1, C8.1, C9.1, J2.2 (VCC), J3.2, R4.2, R5.1, U3.5 (OUT), U4.5 (VCC), U4.17 (VCC), U4.27 (AVCC), U4.38 (VCC), j4.1 (V), j5.1 (V)
/4.2V Bat: BT1.1 (+), C2.1, C3.1, C4.1, R3.1, U1.2 (VDD), U2.3 (V_{BAT}), U3.1 (IN)
/5V USB: C1.1, J1.A9 (VBUS), J1.B9 (VBUS), Q1.1 (G), R7.1, R8.1, U2.4 (V_{DD})
/CE: CE.1 (Pin_1_1), J3.3, U4.40 (PB0)
/CSN: CSN.1 (Pin_1_1), J3.4, U4.41 (PB1)
/LBtn: LBtn.1 (Pin_1_1), U4.25 (PC6), j4.5 (SEL+)
/LXaxis: LXaxis.1 (Pin_1_1), U4.36 (PA1), j4.3 (VRX)
/MISO: J2.9 (MISO), J3.7, MISO.1 (Pin_1_1), U4.2 (PB6)
/MOSI: J2.1 (MOSI), J3.6, MOSI.1 (Pin_1_1), U4.1 (PB5)
/RBtn: RBtn.1 (Pin_1_1), U4.26 (PC7), j5.5 (SEL+)
/RESET: J2.5 (~RST), R5.2, U4.4 (~RESET)
/RYaxis: RYaxis.1 (Pin_1_1), U4.37 (PA0), j5.4 (VRY)
/SCK: J2.7 (SCK), J3.5, SCK.1 (Pin_1_1), U4.3 (PB7)
/U1-Reset: Q1.3 (D), R3.2, SW1.2 (B), U1.1 (RESET), U3.3 (EN)
GNDREF: BT1.2 (-), C1.2, C2.2, C3.2, C4.2, C5.2, C6.2, C7.2, C8.2, C9.2, D1.1 (K), Gnd.1 (Pin_1_1), J1.A12 (GND), J1.B12 (GND), J2.4 (GND), J2.6 (GND), J2.8 (GND), J2.10 (GND), J3.1, Q1.2 (S), R1.2, R2.2, R6.2, R8.2, SW1.1 (A), U1.3 (GND), U2.2 (V_{SS}), U3.2 (GND), U4.6 (GND), U4.18 (GND), U4.28 (GND), U4.39 (GND), j4.2 (Gnd), j4.6 (SEL-), j5.2 (Gnd), j5.6 (SEL-)
unnamed: D1.2 (A), R4.1
unnamed: D2.2 (A), R7.2
unnamed: D2.1 (K), U2.1 (STAT)
unnamed: J1.A5 (CC1), R2.1
unnamed: J1.B5 (CC2), R1.1
unnamed: R6.1, U2.5 (PROG)

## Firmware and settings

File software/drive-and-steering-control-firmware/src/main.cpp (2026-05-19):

#include "motor.h"
#include "rf.h"
#include "usart.h"
#include <RF24.h>
#include <avr/boot.h>
#include <avr/interrupt.h>
#include <avr/io.h>
#include <avr/sleep.h>
#include <avr/wdt.h>
#include <ctype.h>
#include <stdlib.h>
#include <string.h>
#include <util/delay.h>

MotorControlPayload payload = {0, 1900};

int main(void)
{
    // Clear watchdog reset flag and disable watchdog timer.
    MCUSR &= ~(1 << WDRF);
    wdt_disable();
    
    DDRD = 0xFF;
    PORTD |= _BV(PD5);

    sei();
    configureMotorPWM();
    configureSteeringPWM();
    enableUSART();
    configureRFRadio();
    
    while (true)
    {
        readAndPrintRFData(&payload);

        OCR1B = payload.ocrSteering;

        if (payload.ocrMotor >= -15 && payload.ocrMotor <= 15)
        {
            stopMotor();
        }
        else if (payload.ocrMotor < -15 && (!reverseMotor || motorStoped))
        {
            setMotorDirection(false);
        }
        else if (payload.ocrMotor > 15 && (reverseMotor || motorStoped))
        {
            setMotorDirection(true);
        }

        setMotorSpeed(payload.ocrMotor);
    }    
}

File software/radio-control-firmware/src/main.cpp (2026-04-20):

#include "joystick.h"
#include "rf.h"
#include "usart.h"
#include <RF24.h>
#include <avr/boot.h>
#include <avr/interrupt.h>
#include <avr/io.h>
#include <avr/sleep.h>
#include <avr/wdt.h>
#include <stdlib.h>
#include <string.h>
#include <util/delay.h>

int main(void)
{
    // Set DDRC to be all inputs
    DDRC = 0x00;

    // Enable pull up resisotr for PC7.
    PORTC = _BV(PC7);

    enableUSART();
    initializeJoysticks();
    rfConfigureRadio();

    MotorControlPayload payload = {1, 1450};

    while (true)
    {
        int16_t speedValue = readSpeedJoystick();
        uint16_t steeringValue = readSteeringJoystick();

        payload.ocrMotor = speedValue;
        payload.ocrSteering = steeringValue;
        rfTransmitData(payload);
    }
}

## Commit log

2025-08-18 - Adding the rc motor controls project to the repo - Adding the rc car remote control project to the repo
2025-08-24 - Uploading Kicad project - Change delay for shutting off the motor to 500 ms
    [rc-car-kicad.kicad_pcb, rc-car-kicad.kicad_sch]
2025-08-24 - Added new pcb schmatic with a panel that contains boath circuit boards
    [rc-car-panel.kicad_pcb]
2025-08-26 - Updated the panel pcb and schematic - Added a boost functionality - Removed unnecessary usart code - Movied analog reading code into the joystick class
    [rc-car-kicad.kicad_sch, rc-car-panel.kicad_pcb]
2025-08-27 - Reduced the delay time when changing directions to 150 ms - made our deadzone between the values -15 and 15 - Configured the wdt to reset only if data has already been and if data hasnt been receiv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
    [main.cpp]
2025-09-06 - Redesigned power portion of the pcb - Changed the board to atmega164A
    [rc-car-kicad.kicad_pcb, rc-car-kicad.kicad_sch]
2025-09-06 - Made improvements to power and ground plains on the powere pcb - Updated the component labels in the schematic
    [rc-car-kicad.kicad_pcb, rc-car-kicad.kicad_sch]
2025-09-07 - Updated the microcontroller pcb
    [rc-car-kicad.kicad_pcb, rc-car-kicad.kicad_sch]
2025-09-07 - Added testing points for H-Bridge connections to the PCB
    [rc-car-kicad.kicad_pcb, rc-car-kicad.kicad_sch]
2025-09-07 - Modified the header pins a bit on the pcb
    [rc-car-kicad.kicad_pcb, rc-car-kicad.kicad_sch]
2025-09-08 - Updated panelized board. Fixed all design route errors
    [rc-car-kicad.kicad_pcb, rc-car-panel.kicad_pcb]
2025-09-09 - Documented the schematic and created a pdf of the schematic
    [rc-car-kicad.kicad_pcb, rc-car-kicad.kicad_sch]
2025-09-10 - Added an images directory with images of the pcb and the schematic - Added a revision number to the pcb. - Finalized pcb and schematic
    [rc-car-kicad.kicad_pcb, rc-car-kicad.kicad_sch, rc-car-panel.kicad_pcb]
2026-04-20 - Added code docs to all cpp files - Remved boost code - Removed commented code - Clamped the steering values to be 1200 - 1700
2026-05-04 Adding rc-car-remote kicad project to the repo
    [rc-car-remote.kicad_pcb, rc-car-remote.kicad_sch]
2026-05-04 - Adding example readme - Adding temp readme - Adding alterante address for bmw vs jaguar - Changed the speed range to be from -190 to 190 - Updated the min and max values for steering - Fixed commen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
2026-05-15 - Made the steering motor center 1780 - added stl for car parts
    [Car Parts.stl]
2026-05-15 Added section for power cunsumption and schematics
2026-05-18 - Added images for all circuits - changed the remote control microcontroller target to an atmega164A
    [Controller.stl]
2026-05-18 - renamed the software folders to rc-transmitter-firmware and drive-and-steering-control-firmware
2026-05-18 - add the steering sevo control and drive motor control sections
2026-05-20 - Added stl for controller to readme
2026-05-20 - adding other stl
2026-05-20 - Updated stl
2026-05-20 testing stl
2026-05-20 - reuploading stl
2026-05-20 - Trying New stl
2026-05-20 - new stl
2026-05-21 - stl upload attempt again
2026-05-21 - Motor Mount stls
2026-05-21 more car parts stl
2026-05-21 - The rest of the car parts stl
2026-05-24 - Uploading rc car remote gerber files - Updated the 3d models for the rc car circuit. Changed them all to .step
    [rc-car-kicad.kicad_pcb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]
2026-05-24 - Updated the 3d image of the rc car remote circuit
